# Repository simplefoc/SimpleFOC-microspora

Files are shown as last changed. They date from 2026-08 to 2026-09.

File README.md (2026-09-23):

# SimpleFOC-microspora v1.7
This is a compact all-in-one BLDC/Stepper driver board built for the SimpleFOC ecosystem. The project is a direct fork of the [MicroSpora board from RamBros](https://github.com/rambros3d/MicroSpora-SimpleFOC).

📢 NEW: This board is now available in our collaboration with **Makerfabs**: [See more on makerfabs.com](https://www.makerfabs.com/simplefoc-microspora.html)

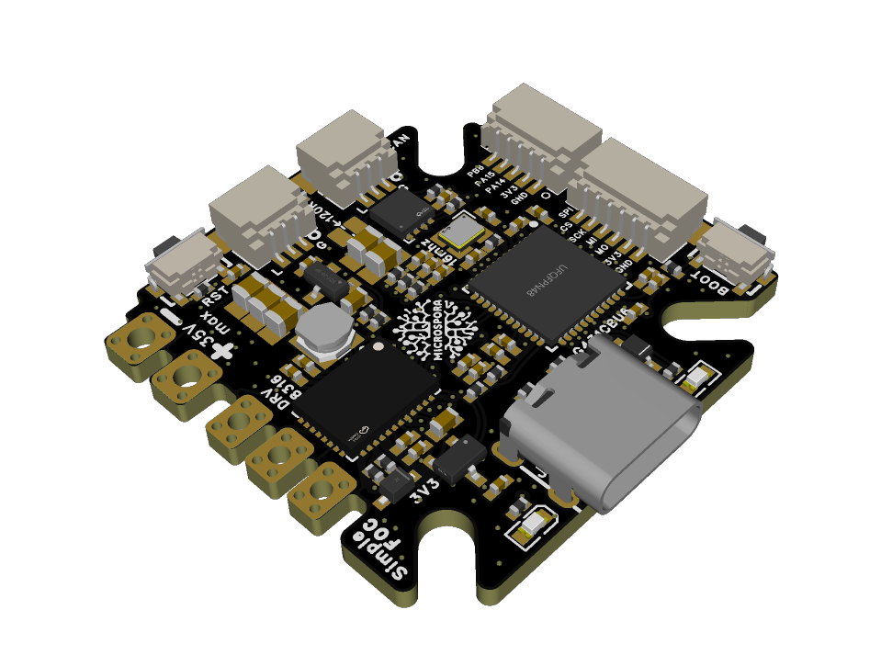
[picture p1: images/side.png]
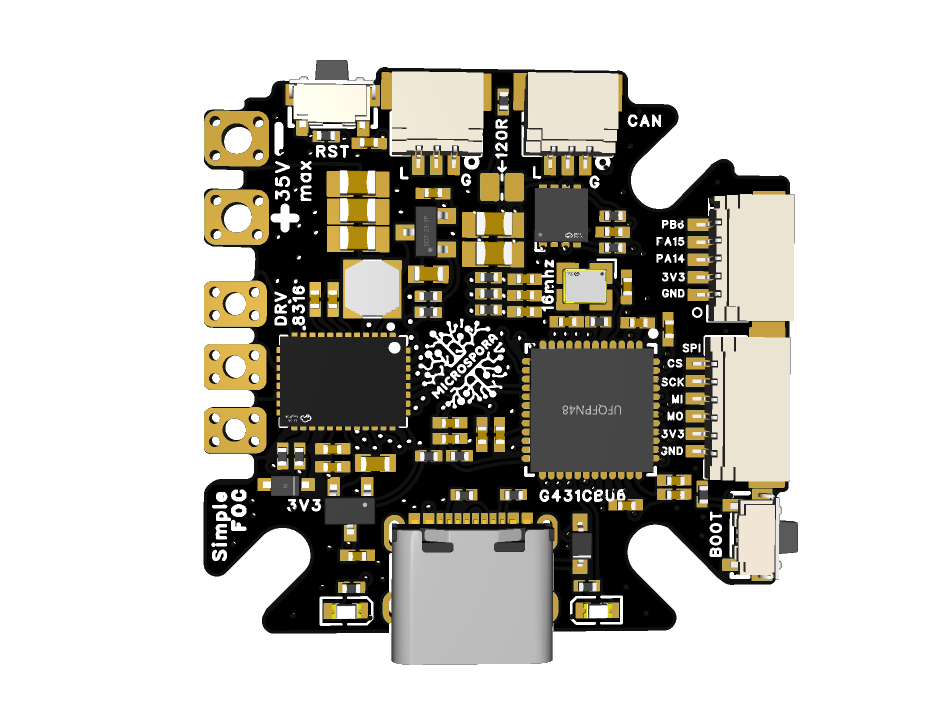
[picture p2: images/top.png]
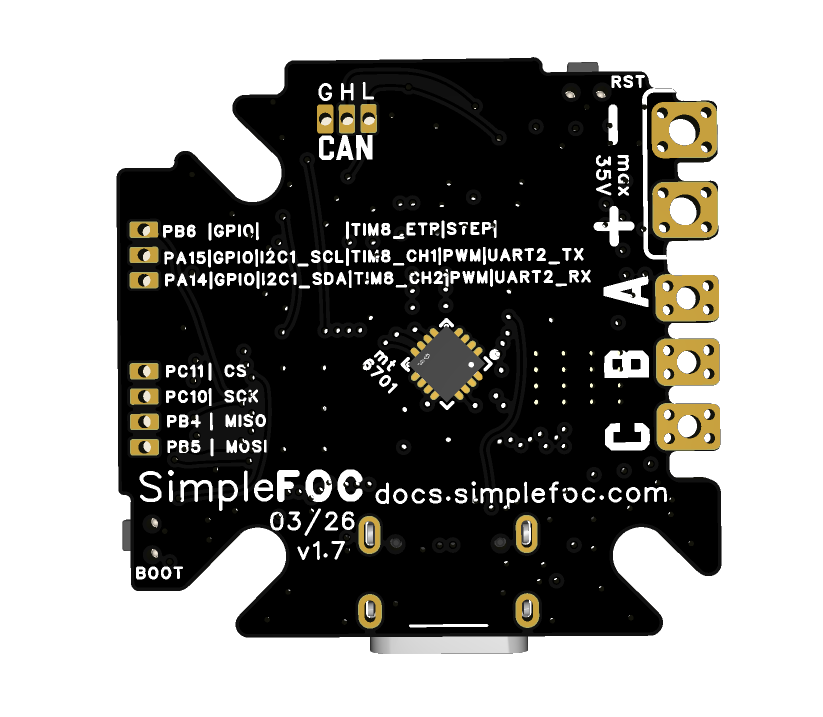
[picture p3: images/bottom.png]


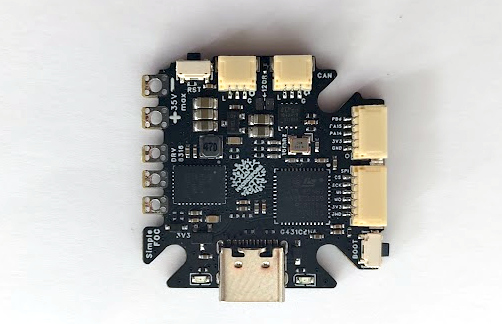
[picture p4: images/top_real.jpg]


## Features
- MCU: STM32G431CBU6
- Driver: DRV8316
  - Power supply: 5-35V
  - Max current: 8A
- Sensing
  - MT6701 magnetic encoder support
  - Built for current and voltage sensing
- Connectivity
  - CAN JST connector with daisy-chain support
  - SPI JST connector
  - I2C / Encoder / GPIO 5-pin JST connector
  - Stemma / Qwiic-style compatible interface
- Compact form factor: 33mm x 34mm
- Fully compatible with the SimpleFOC library
- Designed to be a nice entry point with SimpleFOC 
    - for low-power BLDC motors
    - for stepper motors
- Open-source: [EasyEDA link](https://oshwlab.com/the.skuric/microspora-simplefoc-antun)
- Low-cost: 
    - designed to be affordable for hobbyists and makers
    - At JLCPCB, the board can be manufactured for about 20$ 
    - Available with Makerfabs - see more at [makerfabs.com](https://www.makerfabs.com/simplefoc-microspora.html)

## Getting started with SimpleFOC-microspora

The example firmware and reference code can be found in the [microspora_simplefoc_firmware repository](https://github.com/pollen-robotics/microspora_simplefoc_firmware).

- The firmware repository shows how to get started with the board and use it with the SimpleFOC library.
- For more community discussion and help, you can follow the SimpleFOC community forum and Discord.

## Release log

Release | Date | Description
--- | --- | ---
v0.1 | 2025-05 | Initial public release of the MicroSpora board by [@RamBros](https://github.com/rambros3d/MicroSpora-SimpleFOC)
v1.2 | 2025-07 | Added CAN and additional GPIOs JST connectors, gone from 6-layer to 4-layer PCB
v1.4 | 2025-12 | Added CAN daisy-chain support + two additional JST connectors for SPI and I2C/Encoder/GPIO
v1.5 | 2026-01 | Pinout refining
v1.6 | 2026-04 | Optimising the JST pinout, compatibility with Stemma / Qwiic-style connectors, reintroduced the Reset button
v1.7 | 2026-06 | Changed the sensor placement to the bottom side, much better performance for stepper motors

## Fastening holes

The board has 3 slots allowing for M3/M2 screws to be used for fastening the board to a surface or enclosure. The slots are 3.2mm wide and 5mm long, allowing for some flexibility in placement.

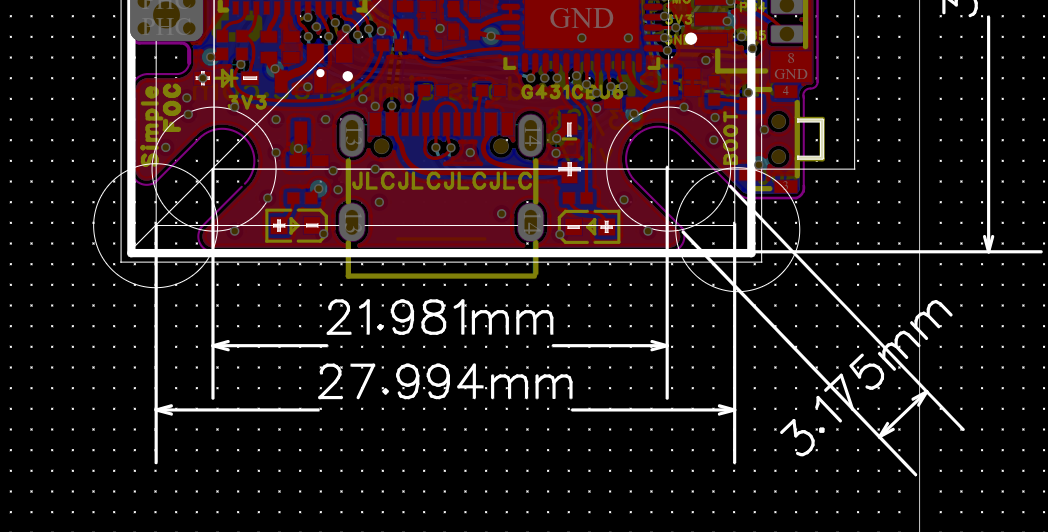
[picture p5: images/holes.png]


The placement will allow for most of the gimbal motors as GM2808, GM3506, GM4108, GM5208 etc. And a simple 3d-printed part cna be used in cases where the motor holes do not match the board holes. 

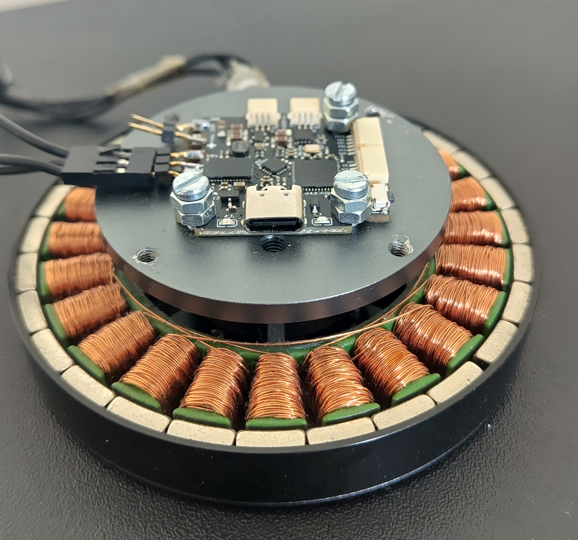
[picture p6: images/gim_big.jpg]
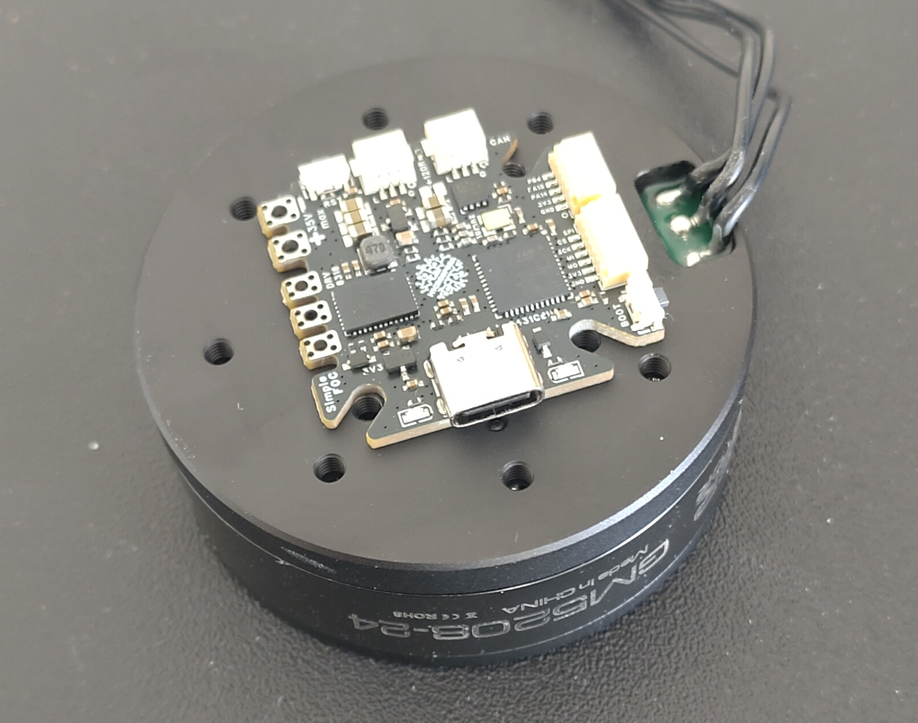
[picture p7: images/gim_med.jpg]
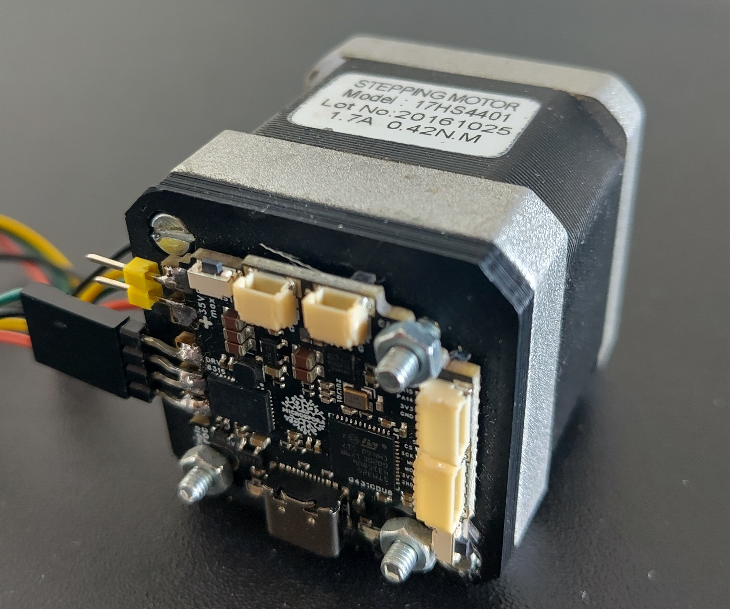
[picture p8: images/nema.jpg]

## Connectors 

The board has a double 3-pin JST connector for daisy-chaining multiple boards using CAN. The order of pins is 

Number | Pin 
--- | --
1| GND
2 | CAN_H 
3 | CAN_L

The board has an additional 6-pin JST connector for SPI, with the following pinout:

Number | Pin|    Function 
--- | -- | ---
1| GND | GND
2|3.3V | 3.3V
3| PB5 | MISO
4| PB4 | MOSI 
5| PC10|  SCK 
6| PC11 | CS 

> Note: This SPI bus is the same one used for the DRV8316 driver, so make sure to configure the driver before you use the SPI bus for other purposes.

Finally, the board has a 5-pin JST connector for I2C, encoder, and GPIO. The pinout is as follows:
Number | Pin| GPIO  | I2C | Timer/Encoder | Step/Dir | PWM input | UART
--- | -- | ---  | ---| ---| ---| ---| ---
1| GND | GND | - | - | -| -| -| -
2| 3.3V | 3.3V | - | - | -| -| -| -
3| PA14 | GPIO | I2C1_SDA | TIM8_CH2 | Dir in| PWM in| USART2_RX
4| PA15 | GPIO | I2C1_SCL | TIM8_CH1 | Dir in| PWM in| USART2_TX
5| PB6 |  GPIO  | -       | TIM8_ETR | Step | -| -

So this connector can be used for I2C, encoder, or GPIO depending on your application. Qwiic / Stemma-style cables can be used to connect to this connector, even though it is 5-pin instead of the usual 4-pin. For most cases teh 4-pin stemma cable will work fine.

## Pinout summary

The board exposes the main motor, sensing, communication, and power-monitoring signals in a compact pin map suitable for SimpleFOC firmware configuration.

### Motor driver and sensing

| Signal | Pin | Description |
| --- | --- | --- |
| PHA_H | PA10 | High-side PWM for phase A |
| PHA_L | PB15 | Low-side PWM for phase A |
| PHB_H | PA9 | High-side PWM for phase B |
| PHB_L | PB14 | Low-side PWM for phase B |
| PHC_H | PA8 | High-side PWM for phase C |
| PHC_L | PB13 | Low-side PWM for phase C |
| ISENS_A | PA0 | Phase A current sense |
| ISENS_B | PA1 | Phase B current sense |
| ISENS_C | PA2 | Phase C current sense |
| VSENS | PB11 | Supply voltage sense input <br> Voltage divider scaling factor is 11.0 (4.7k / 47k) |

### Driver SPI interface

| Signal | Pin | Description |
| --- | --- | --- |
| DRV_MOSI | PB5_ALT1 | DRV8316 SPI MOSI |
| DRV_MISO | PB4_ALT1 | DRV8316 SPI MISO |
| DRV_SCK | PC10 | DRV8316 SPI clock |
| DRV_CS | PC4 | DRV8316 SPI chip select |

### MT6701 magnetic encoder

| Signal | Pin | Description |
| --- | --- | --- |
| ENC_SDO | PA6 | Encoder SPI MISO |
| ENC_NC | PA7 | Not connected (dummy MOSI) |
| ENC_CLK | PA5 | Encoder clock |
| ENC_CS | PA4 | Encoder chip select |

### CAN transceiver

| Signal | Pin | Description |
| --- | --- | --- |
| CAN_RX | PB8 | CAN receive |
| CAN_TX | PB9 | CAN transmit |
| CAN_ENABLE | PC13 | CAN transceiver enable |

The board also has a reset and boot button, as well as a user LED connected to PC6.

## Notes

The full documentation is still being expanded, but the project is already designed for use with the SimpleFOC ecosystem and supports the core features needed for compact low-power BLDC control.

For now, you can follow the discussions on the [SimpleFOC community forum](https://community.simplefoc.com) or the project Discord server for updates and usage tips.

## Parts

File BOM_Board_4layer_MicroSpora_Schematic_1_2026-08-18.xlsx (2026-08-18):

No. | Quantity | Comment | Designator | Footprint | Value | Manufacturer Part | Manufacturer | Supplier Part | Supplier
1 | 6 | 1uF | C23,C25,C26,C37,C40,C41 | C0402 | 1uF | CL05A105KA5NQNC | SAMSUNG(三星) | C52923 | LCSC
2 | 11 | 100nF | C27,C30,C34,C36,C38,C42,C43,C47,C48,C50,C51 | C0402 | 100nF | CL05B104KB54PNC | SAMSUNG(三星) | C307331 | LCSC
3 | 2 | 10pF | C28,C29 | C0402 | 10pF | CL05C100JB5NNNC | SAMSUNG(三星) | C32949 | LCSC
4 | 3 | 22pF | C31,C32,C33 | C0402 | 22pF | 0402CG220J500NT | FH(风华) | C1555 | LCSC
5 | 2 | 22uF | C35,C54 | C0603 | 22uF | CL10A226MQ8NRNC | SAMSUNG(三星) | C59461 | LCSC
6 | 5 | 10uF | C44,C45,C46,C52,C57 | C0805 | 10uF | GRM21BR61H106KE43L | muRata(村田) | C440198 | LCSC
7 | 2 | SM03B-SRSS-TB(LF)(SN) | CN4,CN5 | CONN-SMD_SM03B-SRSS-TB-LF-SN-P |  | SM03B-SRSS-TB(LF)(SN) | JST | C160403 | LCSC
8 | 1 | SM06B-SRSS-TB(LF)(SN) | CN7 | CONN-SMD_SM06B-SRSS-TB-LF-SN |  | SM06B-SRSS-TB(LF)(SN) | JST | C160405 | LCSC
9 | 1 | SM05B-SRSS-TB(LF)(SN) | CN13 | CONN-SMD_SM05B-SRSS-TB-LF-SN |  | SM05B-SRSS-TB(LF)(SN) | JST | C136657 | LCSC
10 | 1 | BZT52B5V1S | D1 | SOD-323_L1.7-W1.3-LS2.6-RD |  | BZT52B5V1S | 宏迦橙 | C19077434 | LCSC
11 | 1 | 1N4148WS | D3 | SOD-323_L1.8-W1.3-LS2.5-RD |  | 1N4148WS | CJ(江苏长电/长晶) | C2128 | LCSC
12 | 1 | 47uH | L1 | IND-SMD_L3.0-W3.0_PRS3015 | 47uH | PRS3015-470MT | FH(风华) | C96151 | LCSC
13 | 1 | yellow | LED2 | LED0603-RD-YELLOW |  | yellow | EVERLIGHT(亿光) | C72038 | LCSC
14 | 1 | red | LED4 | LED0603-RD |  | red | KENTO | C2286 | LCSC
15 | 1 | AO3401A | Q1 | SOT-23_L2.9-W1.3-P1.90-LS2.4-BR |  | AO3401A | AOS | C15127 | LCSC
16 | 5 | 5.1kΩ | R2,R3,R16,R17,R25 | R0402 | 5.1kΩ | 0402WGF5101TCE | UNI-ROYAL(厚声) | C25905 | LCSC
17 | 2 | 100kΩ | R19,R20 | R0402 | 100kΩ | 0402WGF1003TCE | UNI-ROYAL(厚声) | C25741 | LCSC
18 | 4 | 10kΩ | R21,R27,R28,R32 | R0402 | 10kΩ | 0402WGF1002TCE | UNI-ROYAL(厚声) | C25744 | LCSC
19 | 7 | 330Ω | R22,R23,R24,R26,R29,R31,R33 | R0402 | 330Ω | 0402WGF3300TCE | UNI-ROYAL(厚声) | C25104 | LCSC
20 | 1 | 120Ω | R30 | R0402 | 120Ω | 0402WGF1200TCE | UNI-ROYAL(厚声) | C25079 | LCSC
21 | 2 | TSA002A3512A02 | SW2,SW3 | SW-SMD_BZCN_TSA002A35XXX |  | TSA002A3512A02 | BZCN(博众电气) | C2888932 | LCSC
22 | 1 | DRV8316CRRGFR | U1 | VQFN-40_L7.0-W5.0-P0.50-BL-EP5.7 |  | DRV8316CRRGFR | TI(德州仪器) | C5447274 | LCSC
23 | 1 | MT6701QT-STD | U8 | QFN-16_L3.0-W3.0-P0.50-TL-EP1.7 |  | MT6701QT-STD | MagnTek(麦歌恩) | C2913974 | LCSC
24 | 1 | STM32G431CBU6 | U9 | UFQFPN-48_L7.0-W7.0-P0.50-BL-EP |  | STM32G431CBU6 | ST(意法半导体) | C529356 | LCSC
25 | 1 | XC6206P332MR-G | U10 | SOT-23-3_L2.9-W1.6-P1.90-LS2.8-BR |  | XC6206P332MR-G | TOREX(特瑞仕) | C5446 | LCSC
26 | 1 | CA-IF1044VD-Q1 | U11 | DFN-8_L3.0-W3.0-P0.65-BL-EP2.45 |  | CA-IF1044VD-Q1 | Chipanalog(川土微) | C5155979 | LCSC
27 | 1 | TYPE-C 16PIN | USB1 | USB-C-SMD_TYPE-C-6PIN-2MD-073 |  | TYPE-C 16PIN | SHOU HAN(首韩) | C2765186 | LCSC
28 | 1 | 16MHz | X1 | CRYSTAL-SMD_4P-L2.5-W2.0-BL | 16MHz | CJ15-160000810A20 | CJ(江苏长电/长晶) | C2875244 | LCSC

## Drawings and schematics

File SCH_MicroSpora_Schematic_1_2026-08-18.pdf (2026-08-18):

# GPIO Led

# Power Led

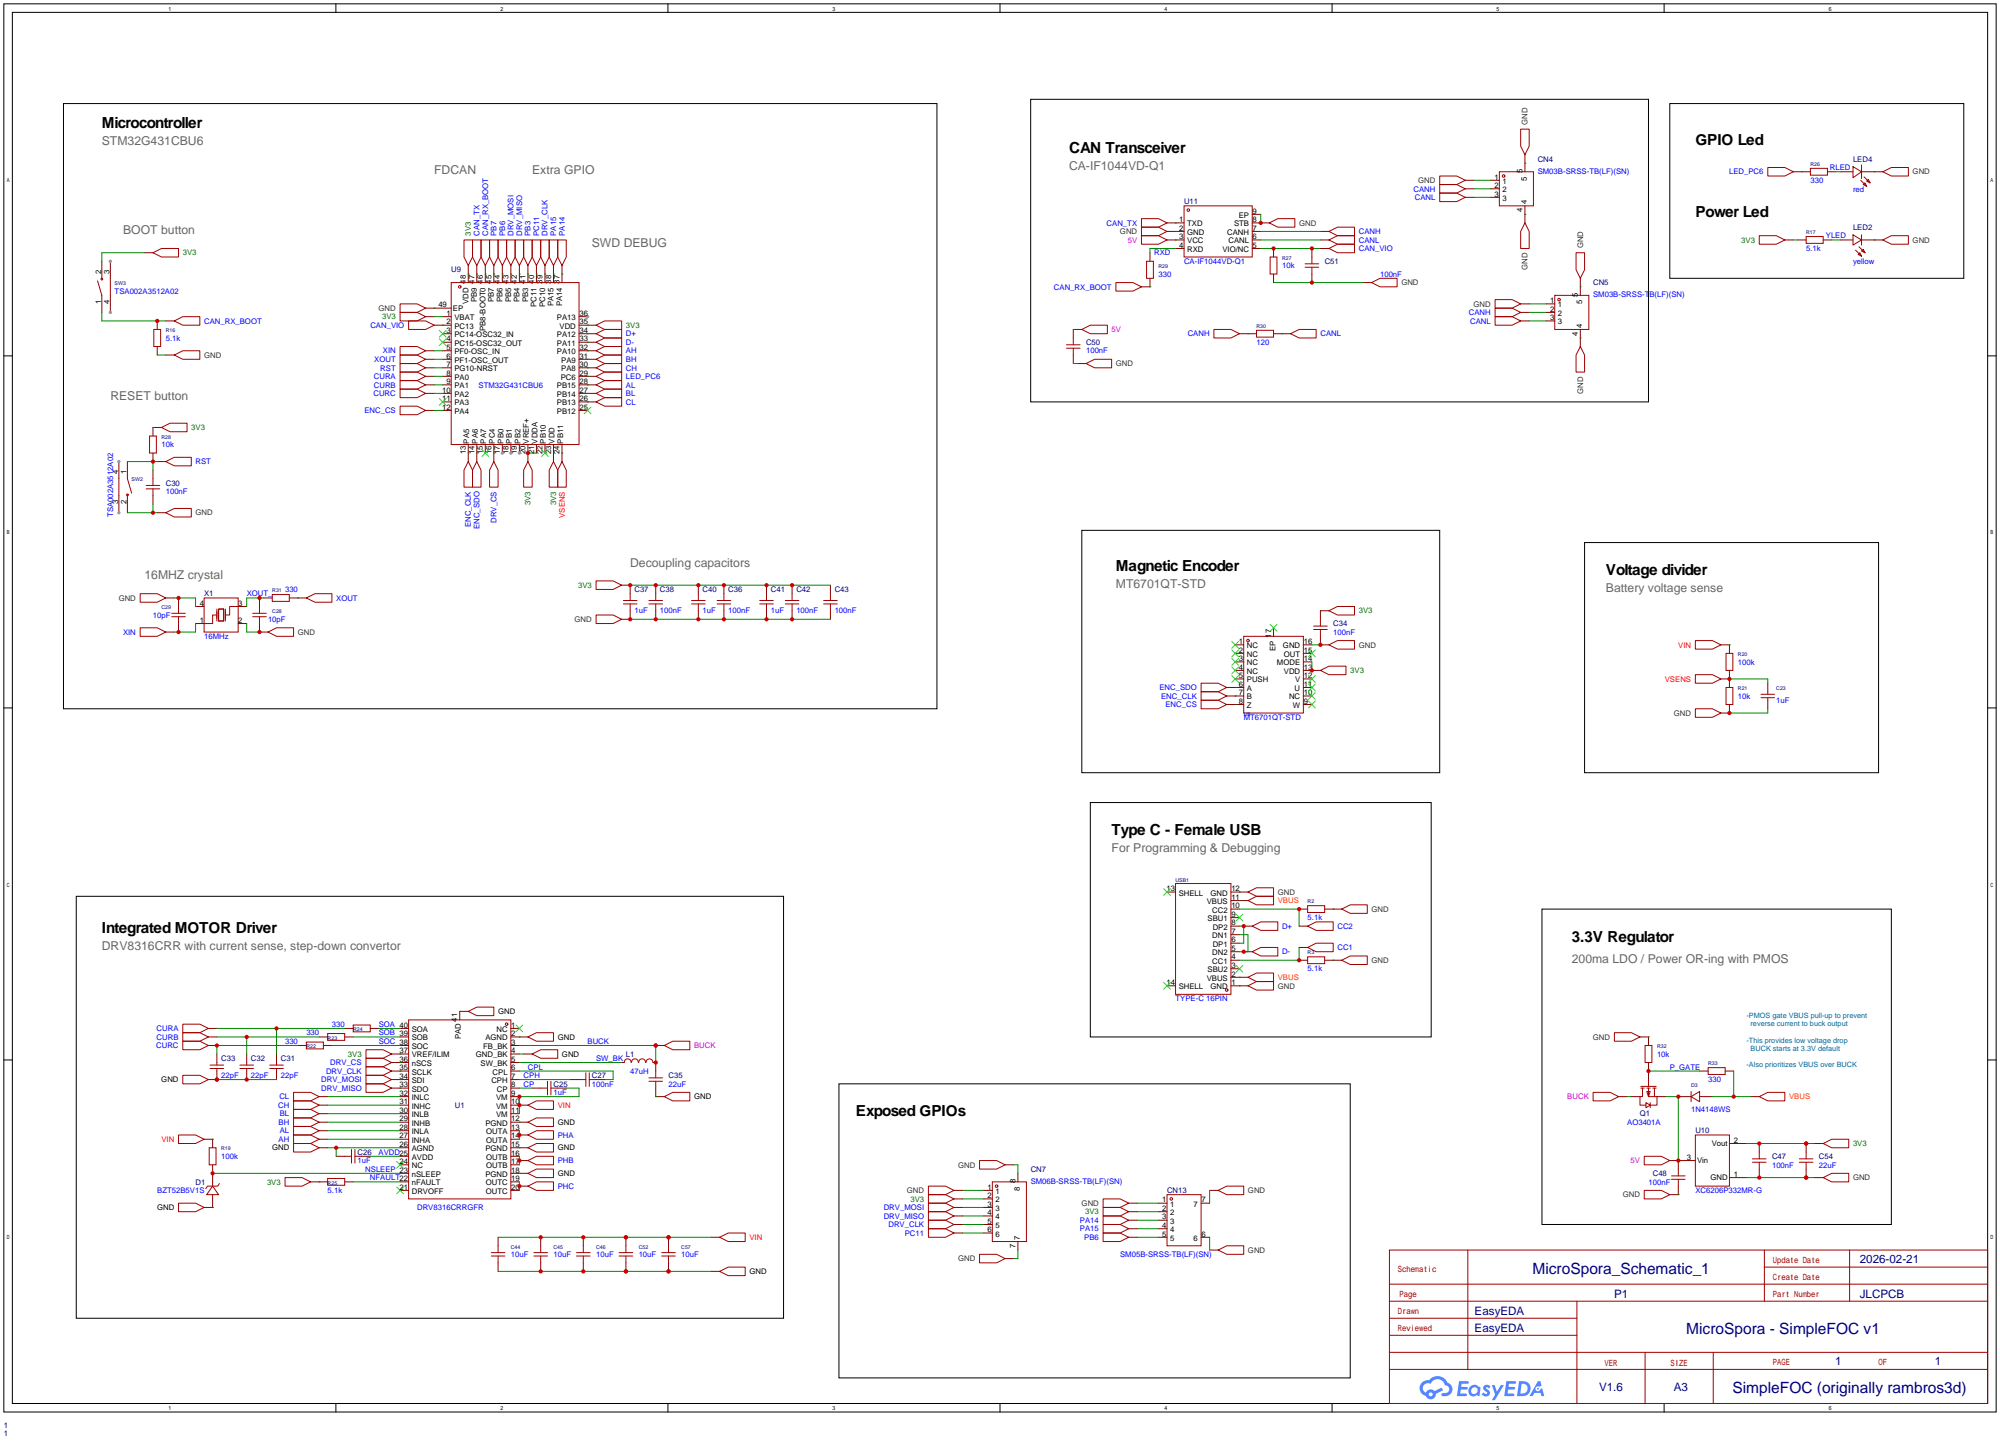
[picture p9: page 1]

SM03B-SRSS-TB(LF)(SN)

PB12 25 PB¹¹ 24 VDD 23 PB¹⁰ 22 VDDA 21 VREF+ 20 PB² 19 PB¹ 18 PB⁰ 17 PC⁴ 16 PA⁷ 15 PA⁶ 14 PA⁵ 13

Integrated MOTOR Driver
DRV8316CRR with current sense, step-down convertor

3.3V Regulator
200ma LDO / Power OR-ing with PMOS

-PMOS gate VBUS pull-up to prevent
reverse current to buck output
-This provides low voltage drop
BUCK starts at 3.3V default
-Also prioritizes VBUS over BUCK

SM06B-SRSS-TB(LF)(SN)

SM05B-SRSS-TB(LF)(SN)

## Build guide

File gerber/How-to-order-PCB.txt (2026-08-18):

How to Order PCB

Please refer to:
https://prodocs.easyeda.com/en/pcb/order-order-pcb/index.html
